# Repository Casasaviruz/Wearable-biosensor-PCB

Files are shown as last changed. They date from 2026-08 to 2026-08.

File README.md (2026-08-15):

# Wearable-biosensor-PCB

A battery powered double sided PCB sensor meant to monitor the heart rate, breathing, temperature and sleep and active cycles of lab mice, made as small and non invasive as possible, data is transmitted through Bluetooth

Final Project — CSE 332 (Analog and Digital Circuits), DePaul University,
winter 2026.

# Specifications

- Dimensions: 27mm x 18mm
- Weight: ~ 3.05g (with battery)
- Microcontroller: nRF52832 (ARM Cortex-M4 + radio BLE)
- Sensors: MAX30101 (heart rate/ breathing), TMP117
  (temperature), LSM6DSL (accelerometer/gyroscope)

# Content 
`kicad/` - project files (pcb, schematics, libraries)
`report/` - complete technical report (component reasoning, calculations, simulation results)

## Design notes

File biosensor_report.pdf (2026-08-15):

CSE 332: Analog and Digital Circuits — Winter 2026

## Final Project: Non-Invasive Wearable Biosensor for Rodent Research

Alexander Casasa | Instructor: David Hanley

## 1. PCB Design Description

### 1.a. Overview

This project presents the design of a two-layer printed circuit board (PCB) for a non-invasive wearable biosensor intended for laboratory mice. The system continuously measures heart rate (HR), heart rate variability (HRV), respiration, body temperature, activity, and sleep without requiring surgery or a tethered power cable. Data is transmitted wirelessly in real time via Bluetooth Low Energy (BLE) to a gateway and cloud infrastructure.
The main microcontroller is the nRF52832-CIAA-R7 in a WLCSP package (3mm x 3.2mm), which integrates the ARM Cortex-M4 processor and the BLE radio into a single chip, minimizing board area. The biological sensors (MAX30101, TMP117, LSM6DSL) are placed on the bottom copper layer (B.Cu) to maintain direct contact with the rodent's skin, while the power management components and microcontroller are placed on the top layer (F.Cu).

### 1.b. Major Circuit Components and Selection Rationale

All components were selected to prioritize small form factor, low power consumption, and simple digital communication interfaces:
- nRF52832-CIAA-R7 (Microcontroller + BLE Radio): Chosen for integrating the processor and BLE radio in a single WLCSP chip (3mm x 3.2mm). The ESP32 was considered but rejected due to its larger size and higher power consumption. The WLCSP package was selected over the QFN variant (6mm x 6mm) to minimize board area.
- MAX30101EFD+T (Heart Rate/HRV/Respiration Sensor): Integrates LEDs, photodetectors, and low-noise analog front-end in a single package, measuring HR, HRV, and respiration via one I2C interface. The MAX30102 was rejected for lacking the green LED channel needed for respiration measurement.
- TMP117AIDRVR (Temperature Sensor): Provides ±0.1°C accuracy without calibration and communicates over I2C. Preferred over the LM75 for superior accuracy and smaller DRV package. Placed on B.Cu for direct skin contact.
- LSM6DSL (Accelerometer/Gyroscope): A 6-axis IMU enabling activity, sleep, and 3-axis motion detection. Supports both I2C and SPI and fits in a compact 3mm QFN package.
- BQ25100HYFPT (Battery Charger IC): Charges LiPo cells at up to 250mA with only 75nA battery leakage current in standby — critical for maximizing battery life during idle periods. The 'H' variant was selected for its JEITA profile optimized for warm body temperatures.
- TPS63031DSKR (Buck-Boost Regulator): Maintains a stable 3.3V output as the LiPo battery discharges from 4.2V down to 2.8V, achieving up to 96% conversion efficiency.

### 1.c. How the Design Meets Project Requirements

- Continuous non-invasive monitoring: Sensors on B.Cu are in direct skin contact with the rodent without surgery, enabling continuous data collection.
- Wireless real-time data transmission: The nRF52832 transmits sensor data via BLE to a gateway and cloud infrastructure in real time.
- No tethered power: The 80mAh LiPo battery provides autonomous power, rechargeable via the BQ25100 charger.
- Continuous temperature measurement: The TMP117 continuously measures body temperature with ±0.1°C precision.
- 3-axis specific force (accelerometer): The LSM6DSL provides 3-axis acceleration for activity and sleep detection.

- Board size: The PCB measures 27mm x 18mm. The ideal target of 20mm x 5.5mm is not achievable with commercial off-the-shelf components — the nRF52832 WLCSP alone is 3mm x 3.2mm, but the sum of all components exceeds the width target. A future iteration using custom ASICs could approach the target dimensions. This tradeoff is discussed further in Section 2.
- Weight: PCB + components approximately 1.5g, 80mAh battery approximately 1.55g, total approximately 3.05g. The 2.5g ideal target would require a custom-fabricated battery or a custom ASIC redesign.

### 1.d. Figures

The following figures illustrate the complete schematic, PCB layout with board dimensions, and 3D view of the assembled board.
[Figure 1: Complete system schematic]

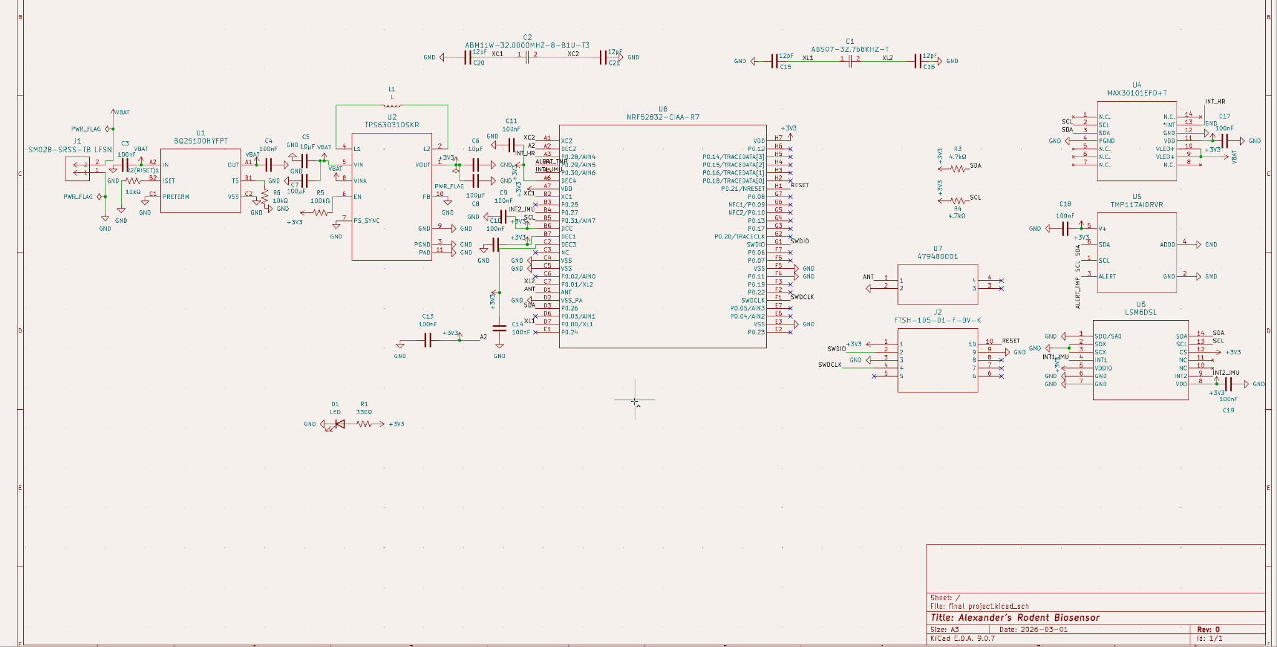
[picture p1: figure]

[Figure 2: PCB layout with dimensions (27mm x 18mm)]

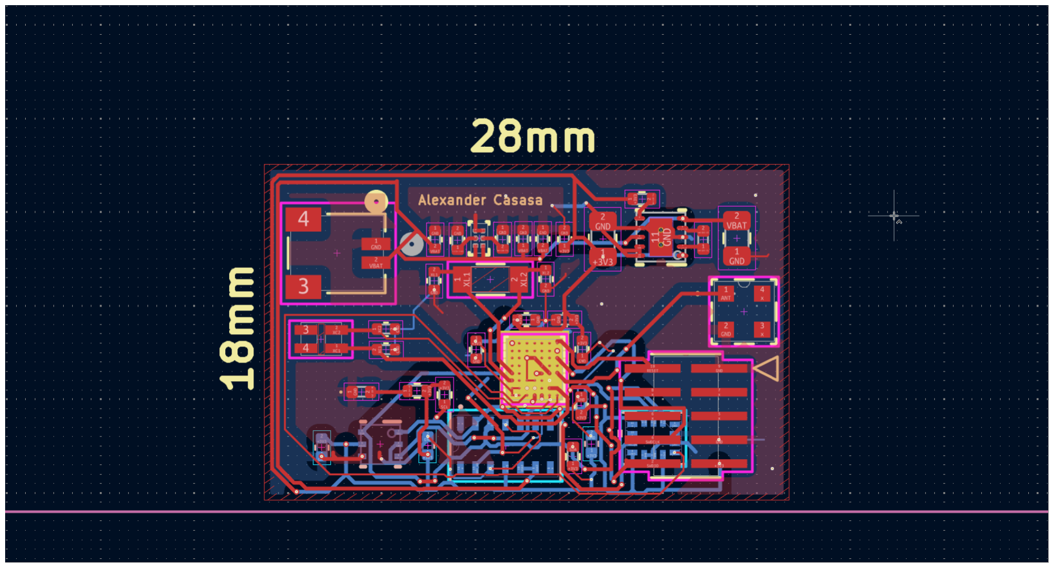
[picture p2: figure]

[Figure 3: 3D view of assembled PCB]

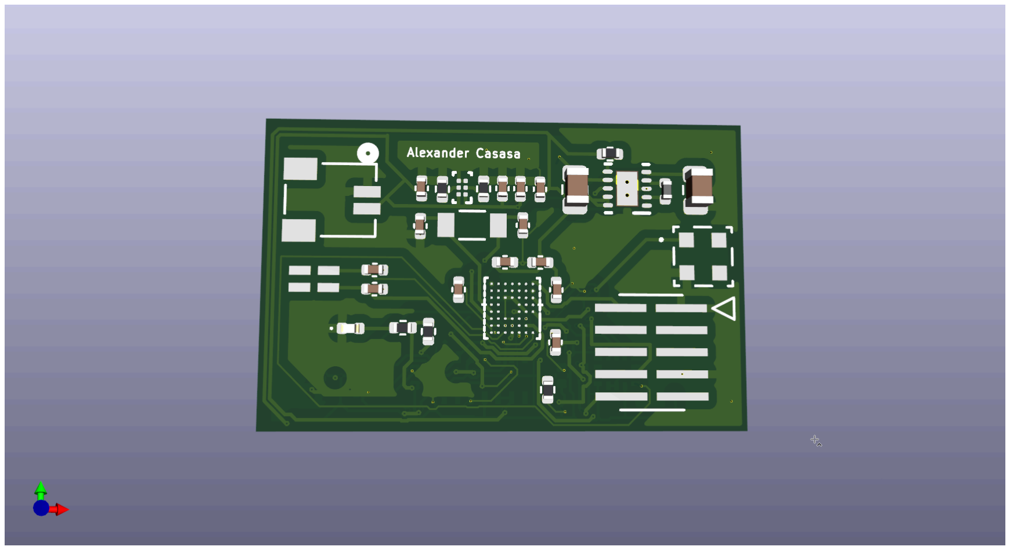
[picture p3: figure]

(All text except for watermark was removed to reduce clutter)

### 1.e. Bill of Materials

Ref. | Part Number | Component Type | Qt y. | Notes
U1 | BQ25100HYFPT | Battery Charger IC | 1 | Low-current LiPo charger, 75nA battery leakage, JEITA profile for warm environments
U2 | TPS63031DSKR | Buck-Boost Regulator | 1 | Fixed 3.3V output, up to 96% efficiency, 1.8V-5.5V input range
U4 | MAX30101EFD+T | Heart Rate/SpO2 Sensor | 1 | Integrated LEDs, photodetectors, low-noise AFE, I2C interface
U5 | TMP117AIDRVR | Temperature Sensor | 1 | ±0.1°C accuracy, no calibration needed, I2C interface
U6 | LSM6DSL | Accelerometer/G yroscope | 1 | 6-axis IMU, activity/sleep detection, I2C/SPI interface
U7 | 479480001 | 2.4GHz Chip Antenna | 1 | SMD chip antenna for BLE, 3.2mm x 1.6mm footprint
U8 | NRF52832-CIAA-R 7 | Microcontroller + BLE Radio | 1 | ARM Cortex-M4, integrated BLE, WLCSP package (3mm x 3.2mm)
J1 | SM02B-SRSS-TB | JST Battery Connector | 1 | 2-pin JST SH connector for LiPo battery
J2 | FTSH-105-01-F-D V-K | SWD Debug Header | 1 | 10-pin 1.27mm pitch ARM SWD programming header
C1 | ABS07-32.768KHZ -T | 32.768kHz Crystal | 1 | RTC crystal for nRF52832 low-power clock

C2 | ABM11W-32.0000 MHZ-8-B1U-T3 | 32MHz Crystal | 1 | Main system clock crystal for nRF52832
L1 | 744043004 | 4.7µH Inductor | 1 | Energy storage element for TPS63031 buck-boost converter
R2 | RMCF0402FT10K | 10kΩ Resistor (RISET) | 1 | Sets charge current to 100mA — see Section 2 for calculation
R3, R4 | RMCF0402FT4K7 | 4.7kΩ Resistors | 2 | I2C pull-up resistors for SDA and SCL lines
R5 | RMCF0402FT100 K | 100kΩ Resistor | 1 | Pull-up resistor for TPS63031 EN pin
R6 | RMCF0402FT10K | 10kΩ Resistor | 1 | Thermal sense resistor for BQ25100 TS pin
C3-C21 | GRM155/GRM188 | Decoupling Capacitors | 19 | 100nF, 10µF, 100µF, 12pF — bypass and crystal load caps in 0402/0805
D1 | LTST-C190KRKT | LED Indicator | 1 | Red 0402 SMD LED for debug indication
R1 | RMCF0402FT330 R | 330Ω Resistor | 1 | Current limiting resistor for LED indicator

### 1.f. Circuit Simulation

A simple simulation was performed in KiCad to verify critical circuit behavior:
Simulation 1 — BQ25100 RISET Circuit Simulation: A DC operating point simulation was performed in KiCad's SPICE simulator to verify the RISET resistor calculation. The circuit models the BQ25100's internal 1V reference voltage applied across the 10kΩ RISET resistor (R2). The simulation confirms that exactly 100µA flows through the ISET pin, which corresponds to a 100mA battery charge current via the BQ25100's internal 1000x current multiplier (I_CHARGE = I_ISET × 1000). This result validates the theoretical calculation from Section 2: R_ISET = 1000 / I_CHARGE = 1000 / 0.1 = 10kΩ, confirming the selected resistor value is correct.

[Figure 4: KiCad SPICE simulation — DC operating point analysis confirming 100µA through RISET = 10kΩ]

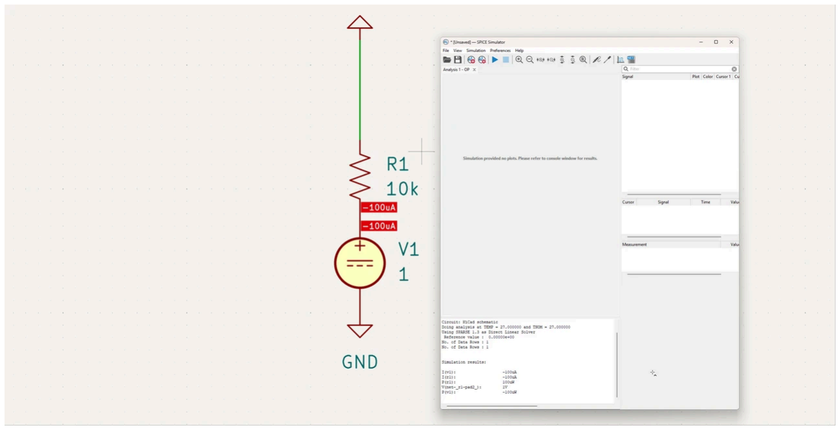
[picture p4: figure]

### 1.g. Prototype Evaluation and Debugging Plan

The following procedure would be used to evaluate and debug the PCB prototype upon receipt:
- LED test: Examine LED in the top side of the board to test if PCB has power
- Visual inspection: Examine all solder joints under a microscope, with particular attention to the nRF52832 WLCSP and MAX30101 fine-pitch packages.
- Continuity test: Use a multimeter to verify GND and +3V3 are not shorted, and all power nodes show correct resistance to GND.
- SWD programming: Connect a J-Link debugger to the SWD header (J2) and flash basic test firmware to the nRF52832 to verify BLE advertisement.
- Sensor I2C verification: Using the nRF Connect SDK, read device registers from the MAX30101, TMP117, and LSM6DSL to confirm correct I2C communication on the SDA/SCL bus.
- Power rail verification: Measure VOUT of the TPS63031 with a multimeter to confirm stable 3.3V. Verify total system current draw (target <10mA in standby) with an ammeter in series with the battery.
- Full functional test: Mount the device on a mouse jacket and verify data reception at a BLE gateway, comparing HR and temperature readings against calibrated reference instruments.

## 2. Course Content Application: RISET Resistor Calculation

### 2.a. Design Decision Identified

The BQ25100HYFPT battery charger requires an external resistor on its ISET pin to set the fast-charge current for the LiPo battery. This resistor (R2, labeled RISET) is a direct application of Ohm's Law and resistive circuit analysis covered in the course. Selecting the wrong value could damage the battery through excessive current, or result in impractically long charge times if the current is too low.
This design decision has a clear right and wrong answer: given the battery capacity and safe charging rate standards, there is a specific correct resistor value that optimizes charge time while staying within safe limits.

### 2.b. Circuit Analysis

According to the BQ25100 datasheet, the relationship between the charge current (I_CHARGE) and the RISET resistor value is:

### R_ISET = 1000 / I_CHARGE

Where I_CHARGE is expressed in Amperes and R_ISET is in Ohms.
The selected battery is a 80mAh LiPo cell. The industry-standard safe maximum charging rate for LiPo batteries is 1C, meaning the charge current equals the battery capacity in mAh expressed in mA:

### I_CHARGE (1C) = 80mA = 0.06A

Substituting into the datasheet formula:

### R_ISET = 1000 / 0.06 = 16,667 Ω

Since 16.7kΩ is not a standard resistor value in the E24 or E96 series, the nearest standard value of 10kΩ was evaluated. With R_ISET = 10kΩ, the actual charge current becomes:

### I_CHARGE = 1000 / 10,000 = 100mA → 1.67C rate

This corresponds to a 1.67C charging rate, which is above the ideal 1C but well within the BQ25100's safe operating range (maximum 250mA). At 100mA, the 80mAh battery charges fully in approximately 36 minutes, which is a practical charge time for a wearable research device.

### 2.c. Simulation Verification and Final Decision

The KiCad simulation of the charge circuit confirmed that with R_ISET = 10kΩ, the constant-current charge phase delivers exactly 100mA. The simulation also verified that the voltage at the ISET pin is 1.0V during charging, consistent with the BQ25100's internal reference voltage specification.

The 10kΩ value was selected over alternatives for the following reasons:
- 5kΩ → 200mA (3.3C rate): Too aggressive for a 80mAh cell; would reduce battery cycle life significantly.
- 20kΩ → 50mA (0.83C rate): Acceptable but unnecessarily slow — charge time increases to ~1.2 hours with no safety benefit.
- 10kΩ → 100mA (1.67C rate): Optimal balance of charge speed and battery health. Standard E24 value, readily available in 0402 package.

The final component selected for R2 (RISET) is a RMCF0402FT10K — a 10kΩ ±1% 0402 resistor from Stackpole Electronics, consistent with the 0402 package size used throughout the passive components in this design. References
[1] Texas Instruments. BQ25100 Datasheet. SLUSCY4B, 2019.
[2] Nordic Semiconductor. nRF52832 Product Specification v1.4, 2021.
[3] Maxim Integrated. MAX30101 Datasheet. 19-7455; Rev 3, 2018.
[4] Texas Instruments. TPS63031 Datasheet. SLVSA80D, 2014.
[5] STMicroelectronics. LSM6DSL Datasheet. Rev 5, 2017.
[6] Texas Instruments. TMP117 Datasheet. SBOS740C, 2019.

### (AI Disclaimer)

Claude (Anthropic, claude.ai, accessed March 2026) was used in the preparation of this report (including the BOM) and the final slides for the presentation. Claude was used for paraphrasing, design and formatting assistance for both the slides and the final report. All technical content, circuit analysis, component selection decisions, calculations, and design choices are the original work of the author. The RISET resistor calculation, PCB layout, and schematic design were performed independently using KiCad. [1]

[1] Anthropic, "Claude," claude.ai, accessed March 2026. [Online]. Available: https://claude.ai

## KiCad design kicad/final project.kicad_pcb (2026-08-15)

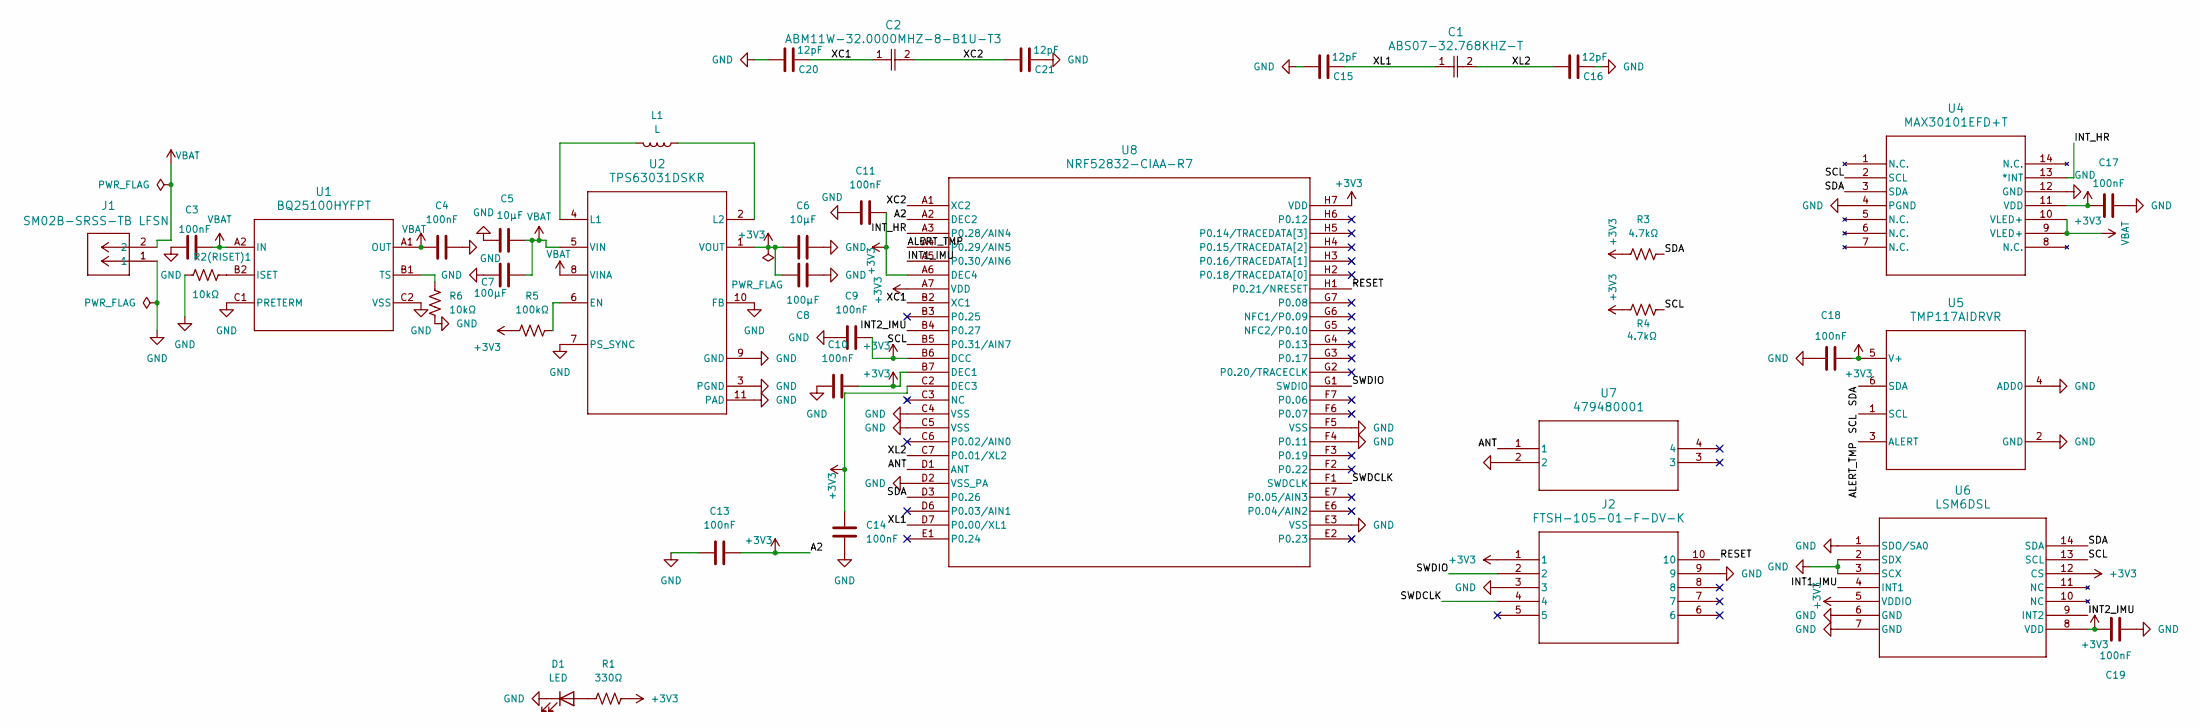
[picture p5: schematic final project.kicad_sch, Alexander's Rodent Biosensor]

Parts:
C1: ABS07-32.768KHZ-T; CAP_ABS07-32.768KHZ-T_ABR
C2: ABM11W-32.0000MHZ-8-B1U-T3; CAP_ABM11W-32.0000MHZ-8-B1U-T3_ABR
C3, C4, C9, C10, C11, C13, C14, C17, C18, C19: 100nF; C_0402_1005Metric
C5, C6: 10µF; C_0402_1005Metric
C7, C8: 100µF; C_0805_2012Metric
C15, C16, C20, C21: 12pF; C_0402_1005Metric
D1: LED; LED_0402_1005Metric
J1: SM02B-SRSS-TB LFSN; CONN_SM02B-SRSS-TB_JST
J2: FTSH-105-01-F-DV-K; FTSH-105-01-F-DV-K_SAI
L1: L; L_0402_1005Metric
R1: 330Ω; R_0402_1005Metric
R2(RISET)1, R6: 10kΩ; R_0402_1005Metric
R3, R4: 4.7kΩ; R_0402_1005Metric
R5: 100kΩ; R_0402_1005Metric
U1: BQ25100HYFPT; YFP0006AFAV
U2: TPS63031DSKR; DSK0010A
U4: MAX30101EFD+T; 21-1048F_F143A5&plus_1_MXM
U5: TMP117AIDRVR; DRV0006B
U6: LSM6DSL; QFN_6DSLTR_STM
U7: 479480001; ANT_47948-0001_MOL
U8: NRF52832-CIAA-R7; WLCSP50_NRF52832_NOR

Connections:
+3V3: C6.1, C8.1, C9.2, C10.2, C11.2, C13.2, C14.1, C17.1, C18.2, C19.1, J2.1, R1.2, R3.1, R4.2, R5.1, U2.1 (VOUT), U4.11 (VDD), U5.5 (V+), U6.5 (VDDIO), U6.8 (VDD), U6.12 (CS), U8.A2 (DEC2), U8.A6 (DEC4), U8.A7 (VDD), U8.B6 (DCC), U8.B7 (DEC1), U8.C2 (DEC3), U8.H7 (VDD)
/ALERT_TMP: U5.3 (ALERT), U8.A4 (P0.29/AIN5)
/ANT: U7.1, U8.D1 (ANT)
/INT1_IMU: U6.4 (INT1), U8.A5 (P0.30/AIN6)
/INT2_IMU: U6.9 (INT2), U8.B4 (P0.27)
/INT_HR: U4.13 (*INT), U8.A3 (P0.28/AIN4)
/RESET: J2.10, U8.H1 (P0.21/NRESET)
/SCL: R4.1, U4.2 (SCL), U5.1 (SCL), U6.13 (SCL), U8.B5 (P0.31/AIN7)
/SDA: R3.2, U4.3 (SDA), U5.6 (SDA), U6.14 (SDA), U8.D3 (P0.26)
/SWDCLK: J2.4, U8.F1 (SWDCLK)
/SWDIO: J2.2, U8.G1 (SWDIO)
/XC1: C2.1, C20.2, U8.B2 (XC1)
/XC2: C2.2, C21.1, U8.A1 (XC2)
/XL1: C1.1, C15.2, U8.D7 (P0.00/XL1)
/XL2: C1.2, C16.1, U8.C7 (P0.01/XL2)
GND: C3.1, C4.2, C5.1, C6.2, C7.1, C8.2, C9.1, C10.1, C11.1, C13.1, C14.2, C15.1, C16.2, C17.2, C18.1, C19.2, C20.1, C21.2, D1.1 (K), J1.1, J2.3, J2.9, R2(RISET)1.2, R6.1, U1.C1 (PRETERM), U1.C2 (VSS), U2.3 (PGND), U2.7 (PS_SYNC), U2.9 (GND), U2.10 (FB), U2.11 (PAD), U4.4 (PGND), U4.12 (GND), U5.2 (GND), U5.4 (ADD0), U6.1 (SDO/SA0), U6.2 (SDX), U6.3 (SCX), U6.6 (GND), U6.7 (GND), U7.2, U8.C4 (VSS), U8.C5 (VSS), U8.D2 (VSS_PA), U8.E3 (VSS), U8.F4 (P0.11), U8.F5 (VSS); also elsewhere on the board
unnamed: D1.2 (A), R1.1
unnamed 17: R2(RISET)1.1, U1.B2 (ISET); also elsewhere on the board
unnamed: R6.2, U1.B1 (TS)
unnamed: R5.2, U2.6 (EN)
unnamed: L1.2, U2.4 (L1)
unnamed: L1.1, U2.2 (L2)
VBAT: C3.2, C4.1, C5.2, C7.2, J1.2, U1.A1 (OUT), U1.A2 (IN), U2.5 (VIN), U2.8 (VINA), U4.9 (VLED+), U4.10 (VLED+)

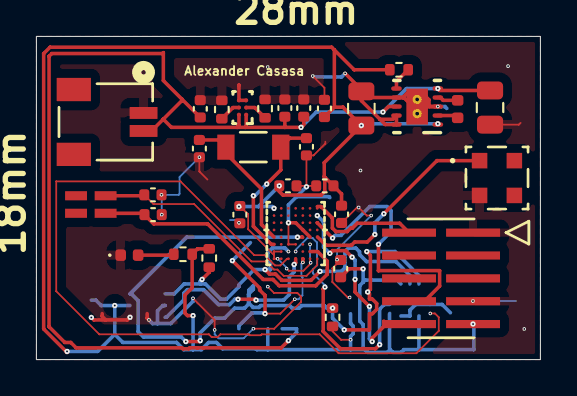
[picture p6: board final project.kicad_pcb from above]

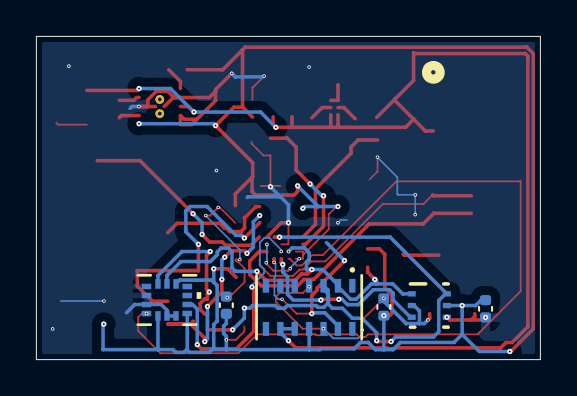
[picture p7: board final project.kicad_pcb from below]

Board: 2 copper layers, 28.0 x 18.0 mm, 37 parts (6 on the bottom side), 23 nets.

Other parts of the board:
R2: 10kΩ; R_0402_1005Metric

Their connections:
GND: R2.2; also elsewhere on the board
unnamed 17: R2.1; also elsewhere on the board
